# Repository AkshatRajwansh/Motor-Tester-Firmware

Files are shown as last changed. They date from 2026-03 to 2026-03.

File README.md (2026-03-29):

This firmware runs on an onboard Teensy 4.1 MCU in a custom designed PCB for an automated servo motor testing machine. You attach a servo, press a button, and it runs 10 tests automatically \- measuring position accuracy, speed, torque, stall point \- and reports everything on the OLED and over serial. 

### It's split into two phases: 
- Phase 1 (no load, pure motion tests) 
- Phase 2 (with a physical load touching the servo arm, torque/force tests).

Hardware Being Used -
| Device | What it does in this project |
|---|---|
| AS5600 | Magnetic encoder \- reads the actual angle of the servo shaft |
| INA219 | Current + voltage sensor \- measures what the servo is drawing |
| HX711 + Load Cell| Measures force being applied to the servo arm |
| SSD1306 OLED | 128x64 display \- shows live test status |
| SW1 Button | User input \- advances between test phases |
| Servo PWM | The servo motor being tested |

The Custom Designed Schematic is as such - 
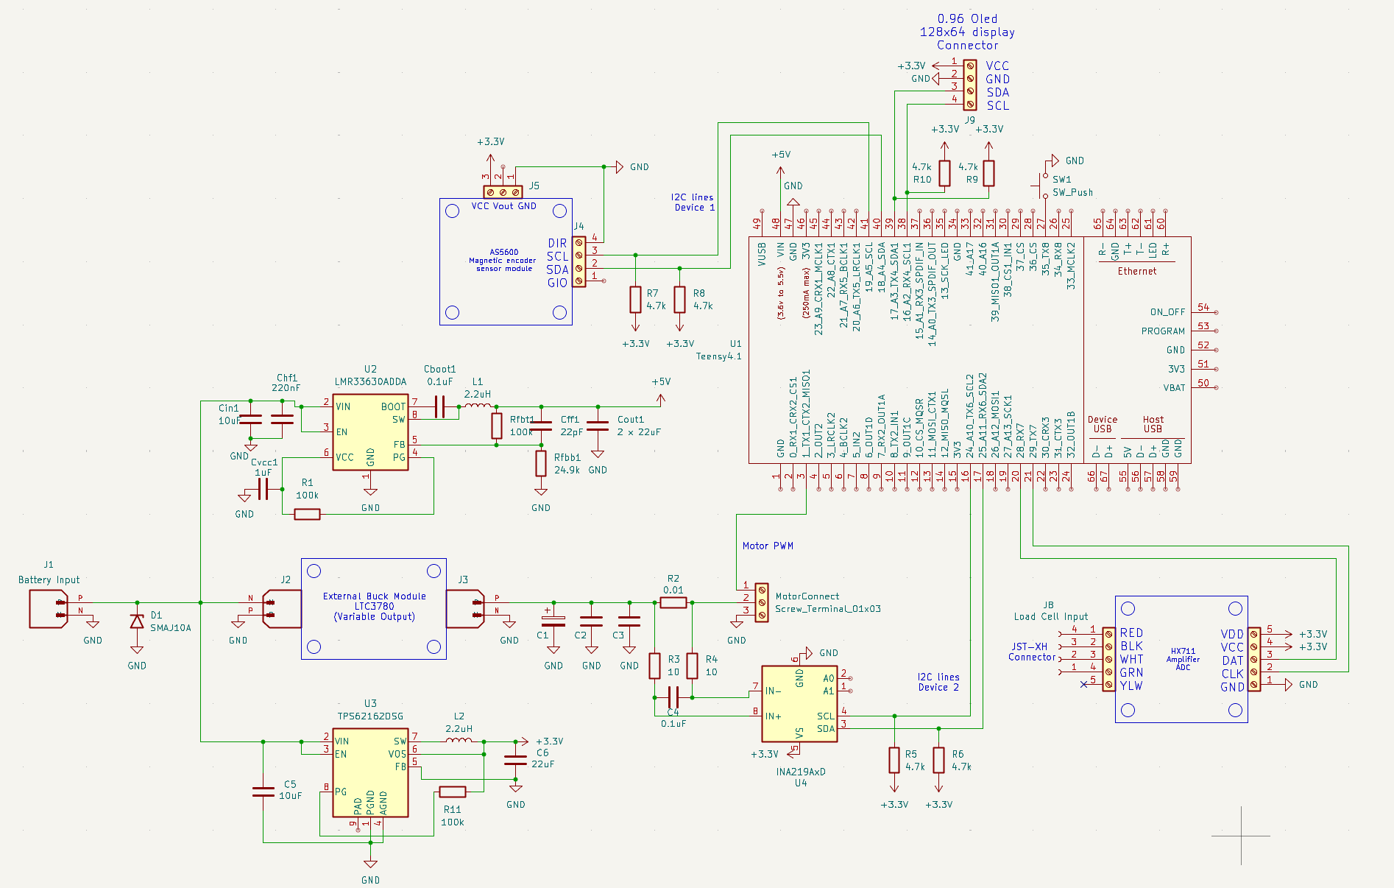
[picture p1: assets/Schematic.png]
PCB Schematic


Here is a detailed explainantion of what is happening in each test and what will be displayed in the OLED screen as well as the serial monitor.

## Phase 1: No Load Tests

### Step 1 - Sweep Test
Moves servo 0°→180°→0° in 2° steps. Records angle, current, and timestamp at every step. Shows if the servo tracks commands accurately while moving and if current spikes at any specific angle.

**OLED Display:**
```
┌─────────────────────────┐
│       SWEEP TEST        │
│ Target:  90.0 deg       │
│ Actual:  89.7 deg       │
│ Current: 210.0 mA       │
│  │
└─────────────────────────┘
```

**Serial Output:**
```
══════════════════════════════════════════════
STEP 1: SWEEP TEST - Angle vs Time vs Current
══════════════════════════════════════════════
  t(ms)  | Target(°) | Actual(°) | Current(mA)
  -------|-----------|-----------|------------
       0 |      0.00 |      0.35 |      142.00
      22 |      2.00 |      2.11 |      198.00
      44 |      4.00 |      3.89 |      210.00
     ...
    1820 |    180.00 |    179.45 |      188.00
```

---

### Step 2 - Position Accuracy
Commands 5 angles (0°, 45°, 90°, 135°, 180°), waits for full settle, then reads actual angle. Computes `error = target - actual` for each. Reveals systematic bias or endpoint inaccuracy.

**OLED Display:**
```
┌─────────────────────────┐
│     POSITION TEST       │
│ Target:   90.0 deg      │
│ Actual:   89.9 deg      │
│ Error:   +0.10 deg      │
└─────────────────────────┘
```

**Serial Output:**
```
══════════════════════════════════════════════
STEP 2: POSITION ACCURACY
══════════════════════════════════════════════
  Target(°) | Actual(°) | Error(°)
  ----------|-----------|----------
       0.00 |      0.35 |   -0.350
      45.00 |     44.82 |   +0.180
      90.00 |     89.91 |   +0.090
     135.00 |    134.76 |   +0.240
     180.00 |    179.44 |   +0.560
  Max absolute error: 0.560°
```

---

### Step 3 - Repeatability
Moves to 90° seven times from 0° each time. Computes mean and standard deviation of the 7 readings. Low stdDev = tight mechanical consistency. High stdDev = backlash or gear play.

**OLED Display:**
```
┌─────────────────────────┐
│     Repeatability       │
│ Run 4: 89.921 deg       │
│ Target: 90 deg          │
└─────────────────────────┘
```

**Serial Output:**
```
══════════════════════════════════════════════
STEP 3: REPEATABILITY (target 90°)
══════════════════════════════════════════════
  Run 1: 89.912°    Run 5: 89.945°
  Run 2: 89.934°    Run 6: 89.908°
  Run 3: 89.898°    Run 7: 89.917°
  Run 4: 89.921°
  Mean:   89.919°
  StdDev: 0.0156°
  Range:  0.0470°
```

---

### Step 4 - Speed & Response
Commands 0°→90° and samples at high speed. Records rise time (how long to reach 90°), overshoot (how far past 90° it went), settling time (when it stops oscillating), and peak current.

**OLED Display:**
```
┌─────────────────────────┐
│       Speed Test        │
│ Ang:91.2  I:540mA       │
│ 0 -> 90 deg             │
└─────────────────────────┘
```

**Serial Output:**
```
══════════════════════════════════════════════
STEP 4: SPEED & RESPONSE (0° → 90°)
══════════════════════════════════════════════
  Rise time (to 90°):  210 ms
  Overshoot:           2.34°
  Settling time:       380 ms
  Peak current:        684.0 mA
```

---

## Phase 2: Load Tests

### Step 6 - Contact Detection
Moves forward slowly in 2° steps until load cell force exceeds threshold. Records the contact angle as the reference point for all torque tests.

**OLED Display:**
```
┌─────────────────────────┐
│     Contact Detect      │
│ Ang:22.0 F:4.2g         │
│ I: 145 mA               │
│ Moving forward...       │
└─────────────────────────┘
```

**Serial Output:**
```
══════════════════════════════════════════════
STEP 6: CONTACT DETECTION
══════════════════════════════════════════════
  Contact angle:  24.00°
  Contact force:  23.4 g
```

---

### Step 7 & 8 - Torque Map
From contact angle, pushes further in steps. At each step records force, angle, current, and voltage. Computes torque (`F × arm length`) and power (`V × I`). Reports peak torque angle with efficiency (`N·mm/mW`).

**OLED Display:**
```
┌─────────────────────────┐
│      TORQUE TEST        │
│ Ang: 36.0  I: 398mA     │
│ Force:   112.5 g        │
│ Torque:  55.18 N.mm     │
└─────────────────────────┘
```

**Serial Output:**
```
══════════════════════════════════════════════
STEP 7 & 8: TORQUE vs ANGLE vs CURRENT
══════════════════════════════════════════════
  Angle(°) | Force(g) | Torque(N·mm) | Current(mA) | Voltage(V) | Power(mW)
  ---------|----------|--------------|-------------|------------|----------
     24.00 |    23.40 |       11.481 |      198.00 |      4.980 |    986.04
     28.00 |    45.80 |       22.467 |      245.00 |      4.975 |   1218.88
     36.00 |   112.50 |       55.181 |      398.00 |      4.955 |   1972.09
     48.00 |   183.20 |       89.865 |      558.00 |      4.920 |   2745.36

  --- Peak Torque Point ---
  Angle:      48.00 deg
  Torque:     89.865 N·mm
  Current:    558.0 mA
  Voltage:    4.920 V
  Power:      2745.36 mW
  Efficiency: 0.0327 N·mm/mW
```

---

### Step 9 - Stall Test
Continues increasing load until both conditions trigger simultaneously: angle stops changing AND current spikes above threshold. Records stall torque, stall current, and stall angle.

**OLED Display:**
```
┌─────────────────────────┐
│       STALL TEST        │
│ Angle:   62.0 deg       │
│ Current:1342.0 mA       │
│ Torque: 118.45 N.mm     │
└─────────────────────────┘
```

**Serial Output:**
```
══════════════════════════════════════════════
STEP 9: STALL TEST
══════════════════════════════════════════════
  Stall angle:   62.00°
  Stall torque:  118.450 N·mm
  Stall current: 1342.0 mA
```

---

### Step 10 - Loaded Hold
Holds 90° for 3 seconds under load. Records position drift and current min/max/avg. Low drift + stable current = good servo. High drift or large current swings = weak holding or internal oscillation.

**OLED Display:**
```
┌─────────────────────────┐
│      TORQUE TEST        │
│ Ang: 89.9  I: 312mA     │
│ Force:    98.2 g        │
│ Torque:   48.16 N.mm    │
└─────────────────────────┘
```

**Serial Output:**
```
══════════════════════════════════════════════
STEP 10: LOADED HOLDING TEST
══════════════════════════════════════════════
  Hold angle:    90.00°
  End angle:     89.87°
  Drift:        -0.1300°
  Avg current:   312.4 mA
  Min current:   287.0 mA
  Max current:   341.0 mA
```

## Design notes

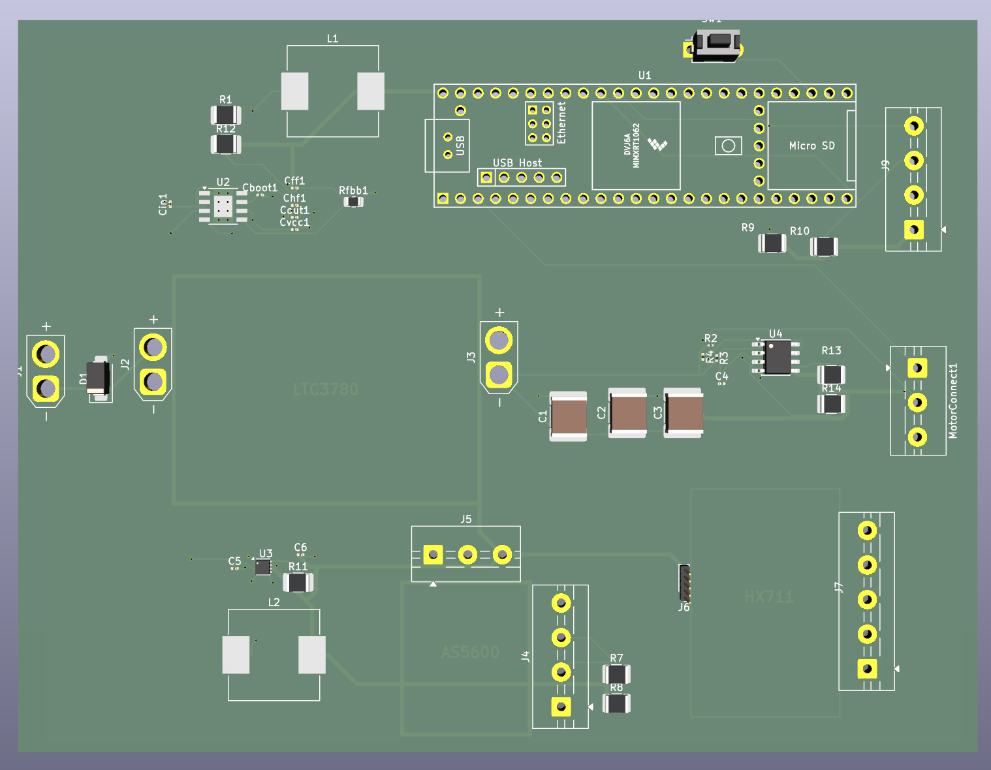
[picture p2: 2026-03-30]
assets/3D View of PCB.png

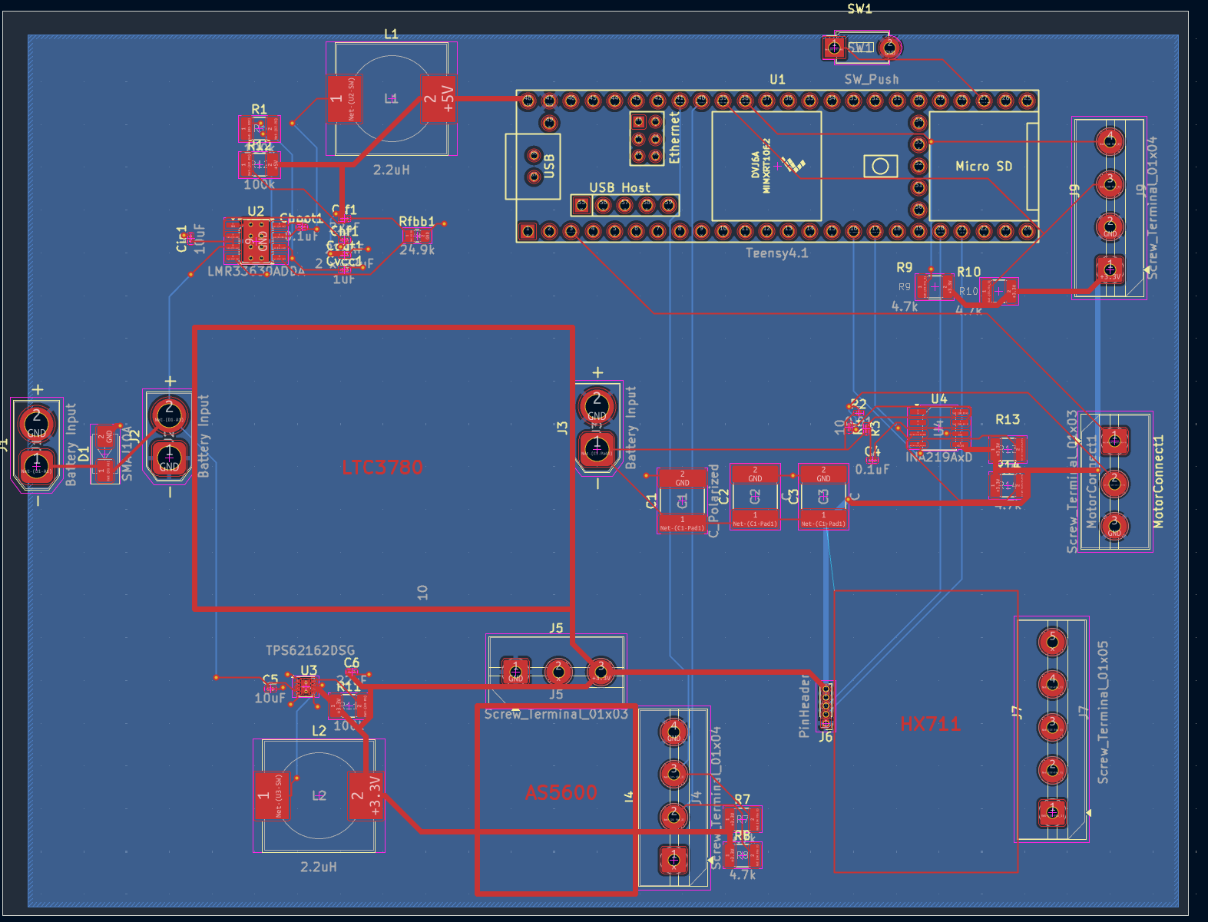
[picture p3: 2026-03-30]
assets/PCB Layout.png

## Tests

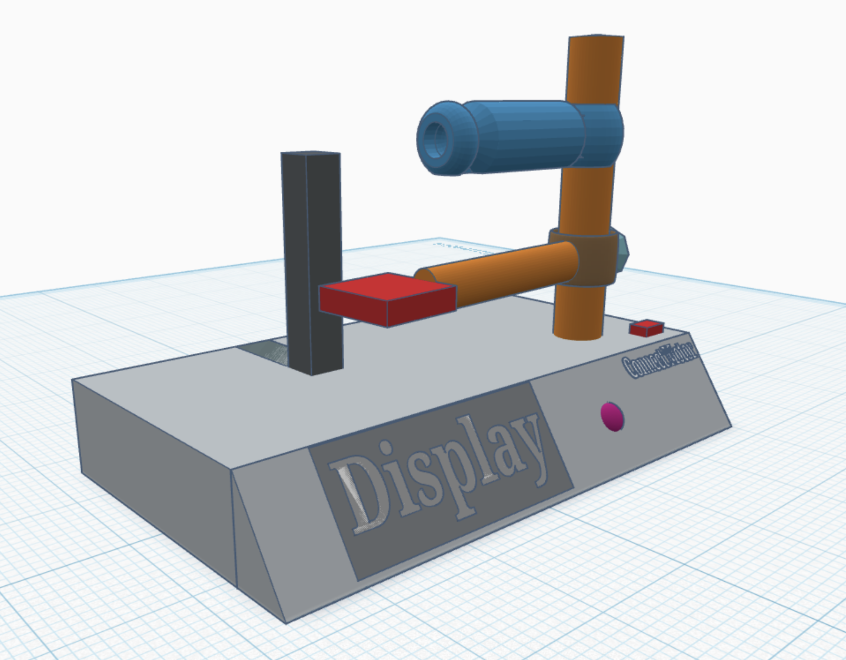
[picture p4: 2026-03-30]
assets/Sketch of Testing Jig.png

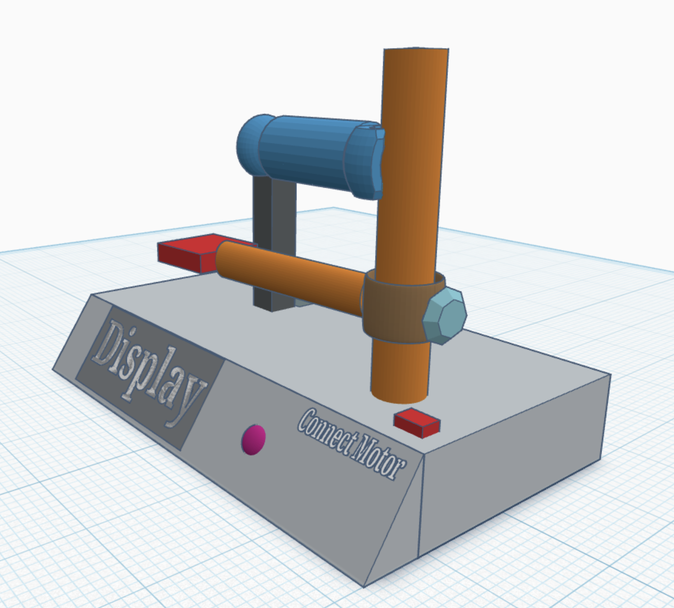
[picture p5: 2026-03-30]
assets/Sketch of Testing Jig 2.png

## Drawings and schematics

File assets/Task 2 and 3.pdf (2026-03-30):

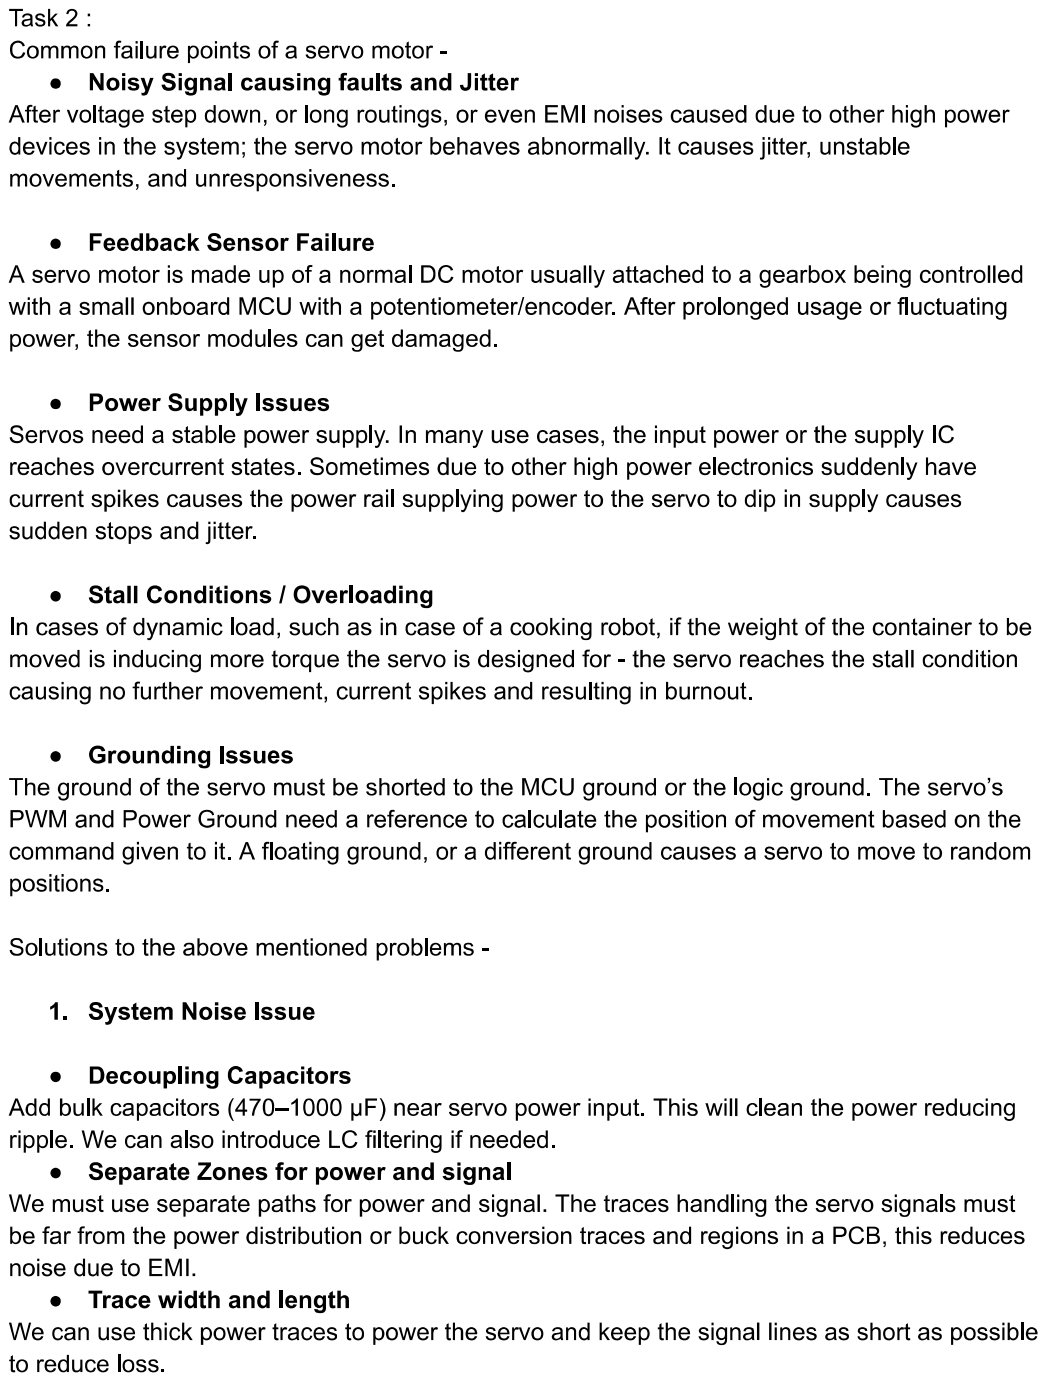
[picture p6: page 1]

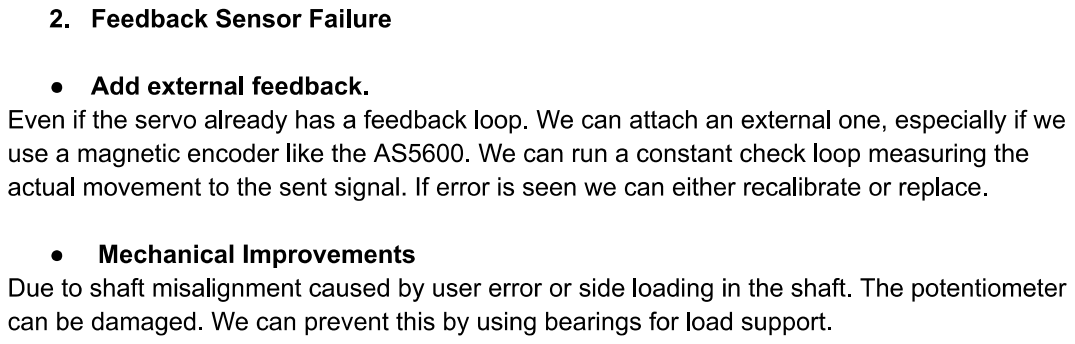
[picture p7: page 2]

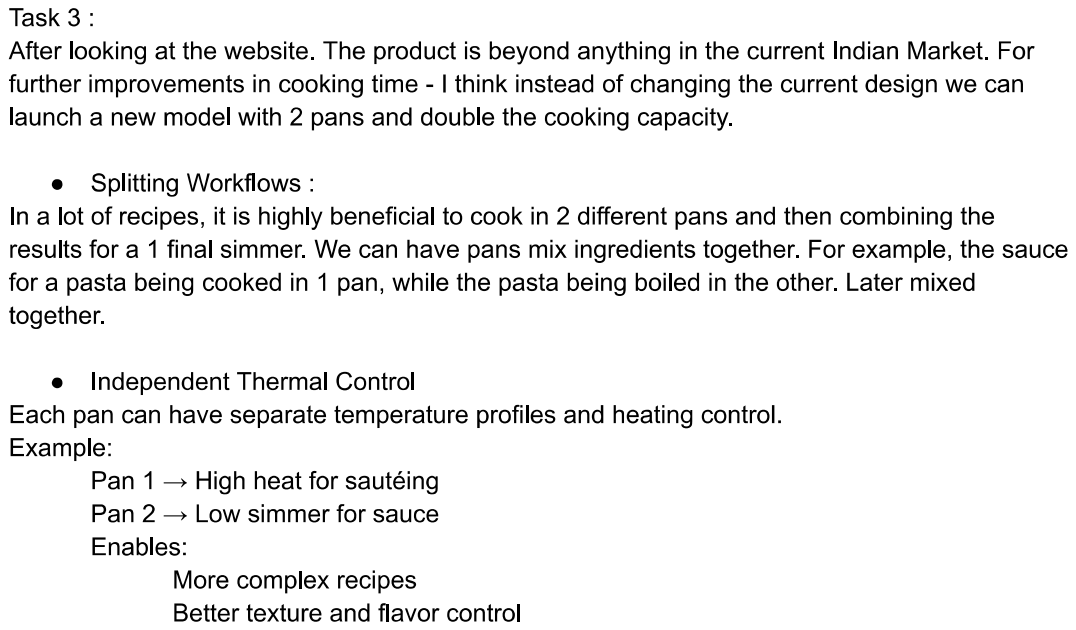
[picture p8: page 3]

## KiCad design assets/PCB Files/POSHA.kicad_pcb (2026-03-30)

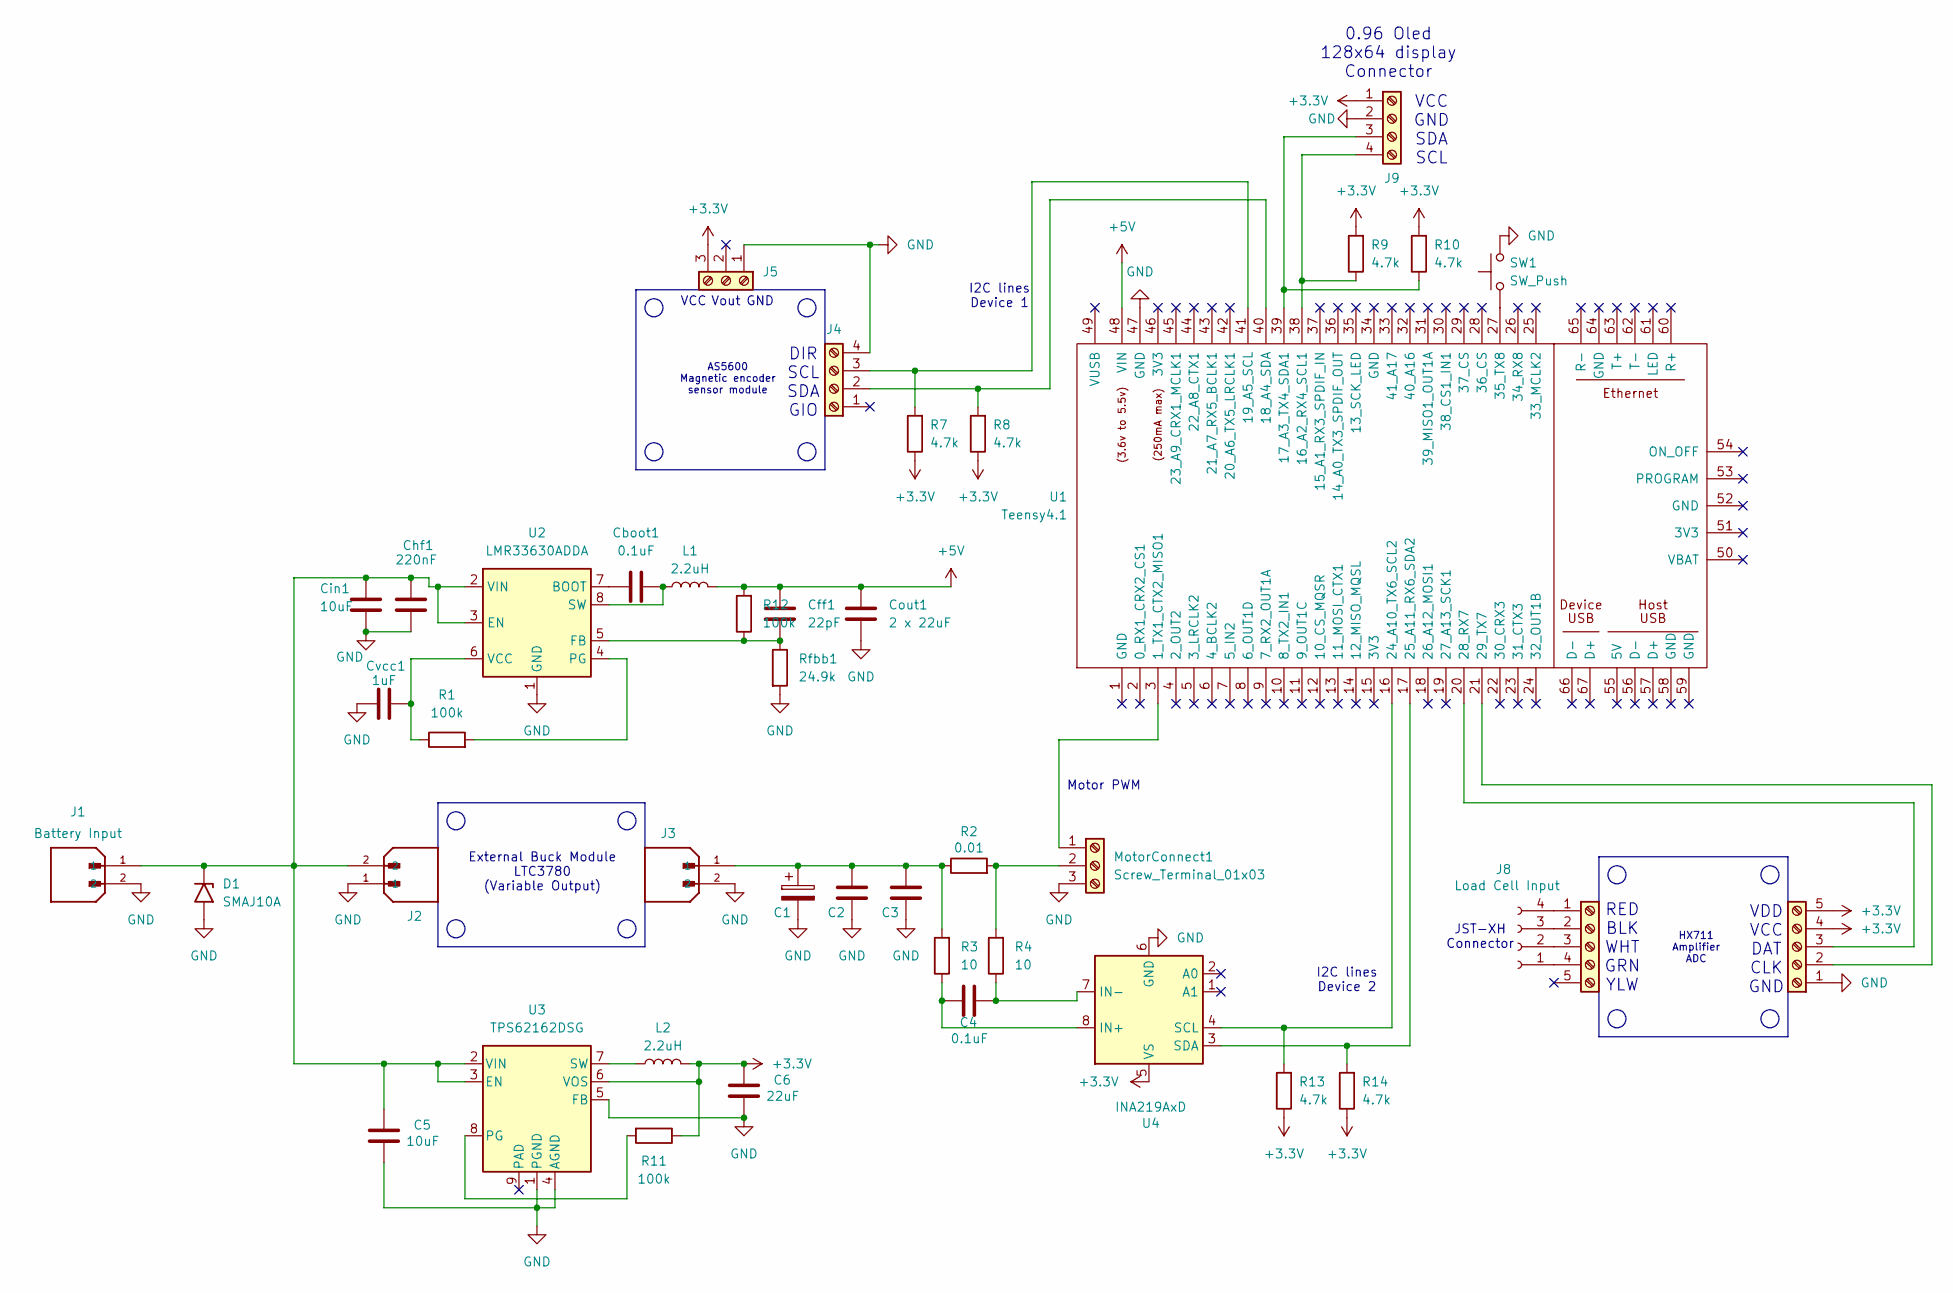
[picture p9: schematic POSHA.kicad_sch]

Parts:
C1: C_Polarized; C_2220_5750Metric_Pad1.97x5.40mm_HandSolder
C2, C3: C; C_2220_5750Metric_Pad1.97x5.40mm_HandSolder
C4: 0.1uF; C_0201_0603Metric
C5: 10uF; C_0201_0603Metric
C6: 22uF; C_0201_0603Metric
Cboot1: 0.1uF; C_0201_0603Metric
Cff1: 22pF; C_0201_0603Metric
Chf1: 220nF; C_0201_0603Metric
Cin1: 10uF; C_0201_0603Metric
Cout1: 2 x 22uF; C_0201_0603Metric
Cvcc1: 1uF; C_0201_0603Metric
D1: SMAJ10A; D_SMA
J1, J2, J3: Battery Input; AMASS_XT30U-F_1x02_P5.0mm_Vertical; PARTREV 1.2
J4, J9: Screw_Terminal_01x04; TerminalBlock_MaiXu_MX126-5.0-04P_1x04_P5.00mm
J5: Screw_Terminal_01x03; TerminalBlock_MaiXu_MX126-5.0-03P_1x03_P5.00mm
J6: Screw_Terminal_01x05; PinHeader_1x05_P1.00mm_Vertical
J7: Screw_Terminal_01x05; TerminalBlock_MaiXu_MX126-5.0-05P_1x05_P5.00mm
J8: Load Cell Input; JST_XH_B4B-XH-A_1x04_P2.50mm_Vertical
L1, L2: 2.2uH; L_Neosid_SM-NE127_HandSoldering
MotorConnect1: Screw_Terminal_01x03; TerminalBlock_MaiXu_MX126-5.0-03P_1x03_P5.00mm
R1, R11, R12: 100k; R_1210_3225Metric_Pad1.30x2.65mm_HandSolder
R2: 0.01; R_01005_0402Metric
R3, R4: 10; R_0201_0603Metric
R7, R8, R9, R10, R13, R14: 4.7k; R_1210_3225Metric
Rfbb1: 24.9k; R_0805_2012Metric
SW1: SW_Push; SW_PUSH_1P1T_6x3.5mm_H5.0_APEM_MJTP1250
U1: Teensy4.1; Teensy41
U2: LMR33630ADDA; Texas_HSOP-8-1EP_3.9x4.9mm_P1.27mm_ThermalVias
U3: TPS62162DSG; WSON-8-1EP_2x2mm_P0.5mm_EP0.9x1.6mm_ThermalVias
U4: INA219AxD; SOIC-8_3.9x4.9mm_P1.27mm

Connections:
+3.3V: C6.1, J5.3, J6.4, J6.5, J9.1, L2.2, R7.1, R8.1, R9.2, R10.2, R11.1, R13.1, R14.1, U3.6 (VOS), U4.5 (VS)
+5V: Cff1.1, Cout1.1, L1.2, R12.2, U1.48 (VIN)
GND: C1.2, C2.2, C3.2, C5.2, C6.2, Chf1.2, Cin1.2, Cout1.2, Cvcc1.2, D1.2 (A2), J1.2, J2.1, J3.2, J4.4, J5.1, J6.1, J9.2, MotorConnect1.3, Rfbb1.2, SW1.2, U1.47 (GND), U2.1 (GND), U2.9 (GND), U3.1 (PGND), U3.4 (AGND), U3.5 (FB), U4.6 (GND)
unnamed: C1.1, C2.1, C3.1, J3.1, R2.1, R3.2
unnamed: C5.1, Chf1.1, Cin1.1, D1.1 (A1), J1.1, J2.2, U2.2 (VIN), U2.3 (EN), U3.2 (VIN), U3.3 (EN)
unnamed: J4.2, R8.2, U1.40 (18_A4_SDA)
unnamed: J4.3, R7.2, U1.41 (19_A5_SCL)
unnamed: J6.2, U1.21 (29_TX7)
unnamed: J6.3, U1.20 (28_RX7)
unnamed: J7.1, J8.4
unnamed: J7.2, J8.3
unnamed: J7.3, J8.2
unnamed: J7.4, J8.1
unnamed: J9.3, R10.1, U1.39 (17_A3_TX4_SDA1)
unnamed: J9.4, R9.1, U1.38 (16_A2_RX4_SCL1)
unnamed: MotorConnect1.1, U1.3 (1_TX1_CTX2_MISO1)
unnamed: MotorConnect1.2, R2.2, R4.2
unnamed: R13.2, U1.16 (24_A10_TX6_SCL2), U4.4 (SCL)
unnamed: R14.2, U1.17 (25_A11_RX6_SDA2), U4.3 (SDA)
unnamed: SW1.1, U1.27 (35_TX8)
unnamed: Cboot1.1, U2.7 (BOOT)
unnamed: Cff1.2, R12.1, Rfbb1.1, U2.5 (FB)
unnamed: R1.2, U2.4 (PG)
unnamed: Cboot1.2, L1.1, U2.8 (SW)
unnamed: Cvcc1.1, R1.1, U2.6 (VCC)
unnamed: R11.2, U3.8 (PG)
unnamed: L2.1, U3.7 (SW)
unnamed: C4.1, R3.1, U4.8 (IN+)
unnamed: C4.2, R4.1, U4.7 (IN-)

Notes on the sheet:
Vout
I2C lines Device 1
VCC
Motor PWM
AS5600 Magnetic encoder sensor module
0.96 Oled 128x64 display Connector
JST-XH Connector
DIR SCL SDA GIO
RED BLK WHT GRN YLW
VDD VCC DAT CLK GND
GND
External Buck Module LTC3780 (Variable Output)
I2C lines Device 2
HX711 Amplifier ADC
VCC GND SDA SCL

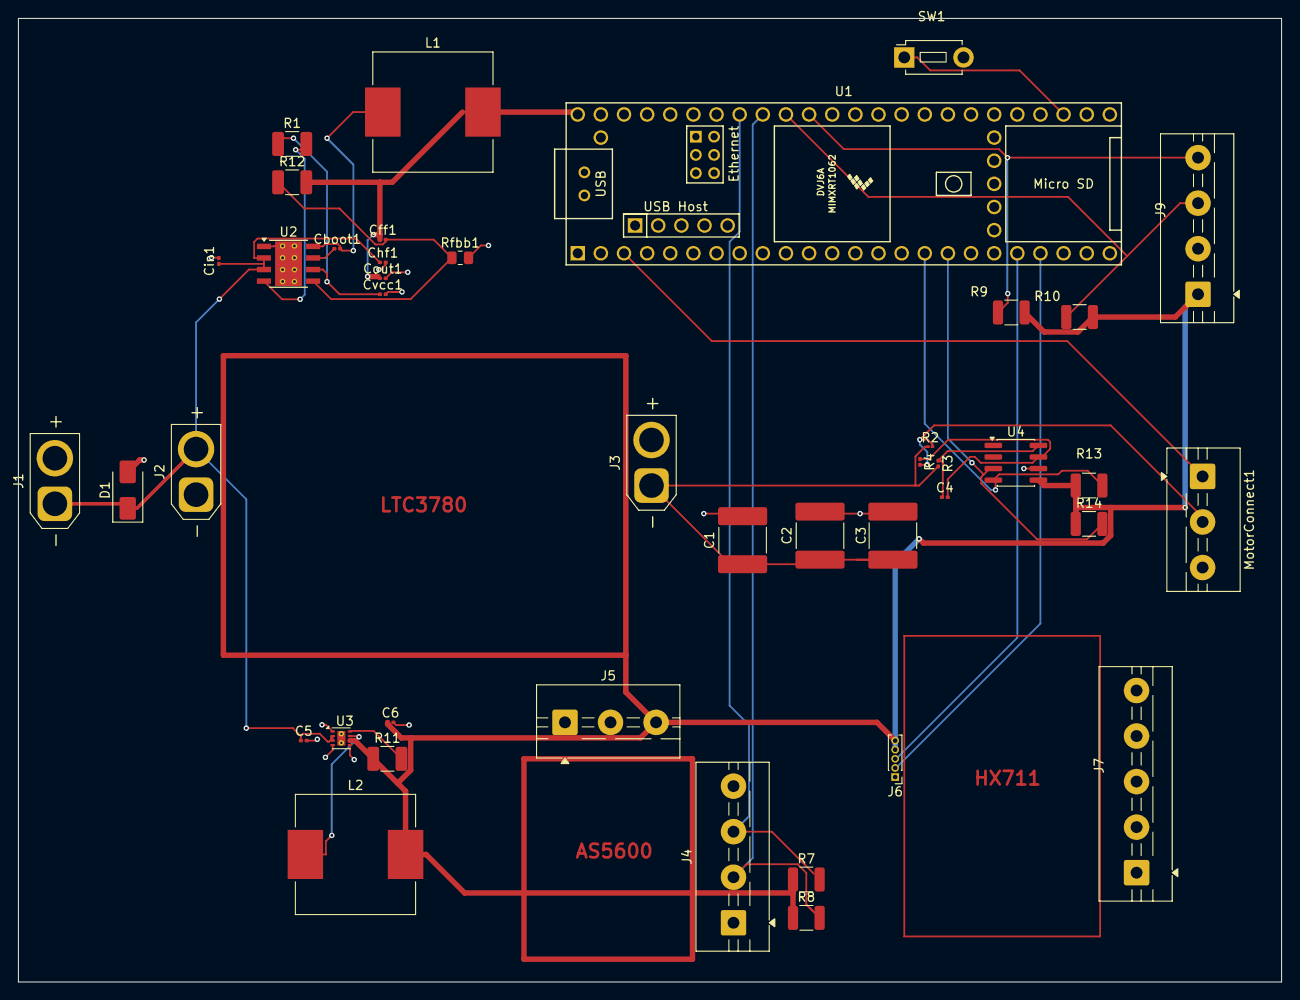
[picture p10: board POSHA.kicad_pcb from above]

Board: 2 copper layers, 138.7 x 105.8 mm, 42 parts (0 on the bottom side), 25 nets.

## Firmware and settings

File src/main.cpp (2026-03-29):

#include <Arduino.h>
#include <Wire.h>
#include <Adafruit_INA219.h>
#include <HX711.h>

#include "config.h"
#include "as5600.h"
#include "display_manager.h"
#include "servo_ctrl.h"
#include "test_results.h"
#include "report.h"

DisplayManager  display;
AS5600Driver    encoder;
ServoController servo;
Adafruit_INA219 ina219(INA219_I2C_ADDR);
HX711           loadCell;

TestResults results;

// define the 8 STeps
enum class AppState {
    WELCOME,
    PHASE1_STARTING,
    STEP1_SWEEP,
    STEP2_POSITION,
    STEP3_REPEAT,
    STEP4_SPEED,
    PHASE1_RESULTS,
    WAIT_PHASE2,
    PHASE2_STARTING,
    STEP6_CONTACT,
    STEP7_TORQUE,
    STEP9_STALL,
    STEP10_HOLD,
    PHASE2_RESULTS,
    DONE
};

AppState appState = AppState::WELCOME;

// button press check, also 50ms hold time so normal noise is not confused with actual press
bool buttonPressed() {
    if (digitalRead(BUTTON_PIN) == LOW) {
        delay(50);
        if (digitalRead(BUTTON_PIN) == LOW) {
            while (digitalRead(BUTTON_PIN) == LOW) delay(10);
            return true;
        }
    }
    return false;
}

void waitForButton() {
    while (!buttonPressed()) delay(20);
}

// Sensor reads
float readCurrentMA() {
    return ina219.getCurrent_mA();
}

float readForceGrams() {
    if (loadCell.is_ready()) {
        float raw = loadCell.get_units(3);  // average of 3 readings, normal usage in library
        return raw;                          
    }
    return 0.0f;
}

float readAngleDeg() {
    return encoder.readZeroedDegrees();
}

// STEP 1: Sweep Test
void runSweepTest() {
    display.showPhaseHeader("1: Sweep Test");
    delay(800);

    results.sweepCount = 0;
    uint32_t startMs = millis();

    // Forward: 0 → 180
    for (float target = 0; target <= 180.0f; target += 2.0f) {
        servo.moveTo(target);
        delay(20);
        float actual  = readAngleDeg();
        float current = readCurrentMA();

        if (results.sweepCount < 200) {
            results.sweepData[results.sweepCount++] = {
                target, actual, current, millis() - startMs
            };
        }
        display.showSweep(actual, current, target);
    }

    // Reverse: 180 → 0
    for (float target = 180.0f; target >= 0; target -= 2.0f) {
        servo.moveTo(target);
        delay(20);
        float actual  = readAngleDeg();
        float current = readCurrentMA();

        if (results.sweepCount < 200) {
            results.sweepData[results.sweepCount++] = {
                target, actual, current, millis() - startMs
            };
        }
        display.showSweep(actual, current, target);
    }

    ReportPrinter::printSweepData(results);
    display.showStatus("Step 1 Done", "Sweep complete", "See serial log");
    delay(1500);
}

// STEP 2: Position Accuracy
void runPositionAccuracyTest() {
    const float targets[] = {0.0f, 45.0f, 90.0f, 135.0f, 180.0f};
    results.posCount = 0;

    for (uint8_t i = 0; i < 5; i++) {
        float target = targets[i];
        servo.moveTo(target);
        delay(SETTLE_TIME_MS);

        float actual = readAngleDeg();
        float error  = target - actual;

        results.posResults[results.posCount++] = {target, actual, error};
        display.showPositionTest(target, actual, error);

        char buf[24];
        snprintf(buf, sizeof(buf), "Target %.0f -> %.2f err", target, error);
#if SERIAL_DEBUG
        Serial.println(buf);
#endif
        delay(600);
    }

    ReportPrinter::printPositionAccuracy(results);
}

// STEP 3: Repeatability 
void runRepeatabilityTest() {
    display.showPhaseHeader("3: Repeatability");
    delay(500);

    results.repeat.count = REPEATABILITY_RUNS;

    for (uint8_t run = 0; run < REPEATABILITY_RUNS; run++) {
        // Start from 0
        servo.moveTo(0);
        delay(300);

        // Move to 90
        servo.moveTo(90);
        delay(SETTLE_TIME_MS);

        float actual = readAngleDeg();
        results.repeat.positions[run] = actual;

        char buf[28];
        snprintf(buf, sizeof(buf), "Run %d: %.3f deg", run + 1, actual);
        display.showStatus("Repeatability", buf,
                           run == 0 ? "Target: 90 deg" : nullptr);
#if SERIAL_DEBUG
        Serial.println(buf);
#endif
        delay(400);
    }

    results.repeat.mean   = computeMean(results.repeat.positions, REPEATABILITY_RUNS);
    results.repeat.stdDev = computeStdDev(results.repeat.positions,
                                           REPEATABILITY_RUNS, results.repeat.mean);
    ReportPrinter::printRepeatability(results);
}

// STEP 4: Speed & Response 
void runSpeedTest() {
    display.showPhaseHeader("4: Speed Test");
    delay(500);

    servo.moveTo(0);
    delay(400);

    float    peakI     = 0;
    float    peakAngle = 0;
    uint32_t t0        = millis();
    uint32_t tSettle   = 0;
    bool     reached90 = false;
    uint32_t t90       = 0;

    servo.moveTo(90);

    // Sample for 2 seconds after command
    uint32_t sampleEnd = millis() + 2000;
    while (millis() < sampleEnd) {
        float angle   = readAngleDeg();
        float current = readCurrentMA();

        if (current > peakI)    peakI    = current;
        if (angle   > peakAngle) peakAngle = angle;
        if (!reached90 && angle >= 90.0f) {
            reached90 = true;
            t90 = millis() - t0;
        }

        char buf[28];
        snprintf(buf, sizeof(buf), "Ang:%.1f I:%.0fmA", angle, current);
        display.showStatus("Speed Test", buf, "0 -> 90 deg");
    }

    // Measure settle: within ±1° of 90 after peak
    float finalAngle = readAngleDeg();
    float overshoot  = max(0.0f, peakAngle - 90.0f);

    // Crude settle time: wait until stable within 0.5°
    uint32_t settleStart = millis();
    uint32_t settleTime  = 0;
    bool settled = false;
    while (millis() - settleStart < 1500 && !settled) {
        float a = readAngleDeg();
        if (abs(a - 90.0f) < 0.5f) {
            settleTime = millis() - t0;
            settled = true;
        }
        delay(10);
    }

    results.speed = {t90, overshoot, settleTime, peakI};
    ReportPrinter::printSpeedResponse(results);
}

// ── STEP 6: Contact Detection ─────────────────────────────────
void runContactDetection() {
    display.showPhaseHeader("6: Contact Detect");
    display.showStatus("Contact Detect", "Attach load now", "Move slowly fwd");
    delay(2000);

    servo.moveTo(0);
    delay(400);

    float contactAngle = 0;
    float contactForce = 0;
    bool  found = false;

    for (float angle = 0; angle <= 180.0f && !found; angle += SWEEP_STEP_DEG) {
        servo.moveTo(angle);
        delay(SWEEP_STEP_DELAY_MS);

        float force   = readForceGrams();
        float current = readCurrentMA();

        char buf[28];
        snprintf(buf, sizeof(buf), "Ang:%.1f F:%.1fg", angle, force);
        display.showStatus("Contact Detect", buf, "Moving forward...");

        if (force > LOAD_CONTACT_THRESHOLD_G) {
            contactAngle = angle;
            contactForce = force;
            found = true;
        }
    }

    results.contact = {contactAngle, contactForce};

    if (found) {
        char buf[32];
        snprintf(buf, sizeof(buf), "Contact @ %.1f deg", contactAngle);
        display.showStatus("Contact Found!", buf);
        Serial.printf("[CONTACT] Angle: %.2f°  Force: %.1f g\n",
                      contactAngle, contactForce);
    } else {
        display.showStatus("Contact Detect", "No contact found!", "Check load cell");
        Serial.println("[CONTACT] No contact detected — check load cell calibration");
        delay(2000);
    }
    delay(1000);
}

// STEP 7 & 8: Torque vs Angle vs Current
void runTorqueTest() {
    display.showPhaseHeader("7&8: Torque Map");
    delay(500);

    results.torqueCount = 0;
    float startAngle = results.contact.contactAngleDeg;

    for (float angle = startAngle; angle <= 180.0f && results.torqueCount < 50;
         angle += SWEEP_STEP_DEG * 2) {

        servo.moveTo(angle);
        delay(SWEEP_STEP_DELAY_MS * 2);

        float force   = readForceGrams();
        float current = readCurrentMA();
        // Torque = Force[N] × Arm[m] ; force in grams → N: /1000 * 9.81
        // ARM_LENGTH_MM → m: /1000
        float torqueNmm = (force / 1000.0f * 9.81f) * ARM_LENGTH_MM;

        results.torqueData[results.torqueCount++] = {angle, force, torqueNmm, current};
        display.showTorque(angle, force, torqueNmm, current);

        Serial.printf("[TORQUE] Ang:%.1f° F:%.1fg Tq:%.3fN·mm I:%.1fmA\n",
                      angle, force, torqueNmm, current);
    }

    ReportPrinter::printTorqueData(results);
}

// STEP 9: Stall Test 
void runStallTest() {
    display.showPhaseHeader("9: Stall Test");
    delay(500);

    float lastAngle     = readAngleDeg();
    float stallAngle    = 0;
    float stallTorque   = 0;
    float stallCurrent  = 0;
    bool  stalled       = false;

    for (float angle = results.contact.contactAngleDeg;
         angle <= 180.0f && !stalled;
         angle += SWEEP_STEP_DEG) {

        servo.moveTo(angle);
        delay(SWEEP_STEP_DELAY_MS + 20);

        float actualAngle = readAngleDeg();
        float force       = readForceGrams();
        float current     = readCurrentMA();
        float torque      = (force / 1000.0f * 9.81f) * ARM_LENGTH_MM;

        display.showStall(actualAngle, current, torque);

        bool angleStuck   = abs(actualAngle - lastAngle) < STALL_ANGLE_DEAD_DEG;
        bool currentSpike = current > STALL_CURRENT_MA;

        if (angleStuck && currentSpike) {
            stallAngle   = actualAngle;
            stallTorque  = torque;
            stallCurrent = current;
            stalled      = true;
            Serial.printf("[STALL] Detected at %.2f°, Tq=%.3f N·mm, I=%.1f mA\n",
                          stallAngle, stallTorque, stallCurrent);
        }

        lastAngle = actualAngle;
    }

    if (!stalled) {
        // Record whatever we got at the end
        stallAngle   = readAngleDeg();
        stallCurrent = readCurrentMA();
        float f      = readForceGrams();
        stallTorque  = (f / 1000.0f * 9.81f) * ARM_LENGTH_MM;
        Serial.println("[STALL] No stall detected before 180°");
    }

    results.stall = {stallAngle, stallTorque, stallCurrent};
    ReportPrinter::printStall(results);
}

// STEP 10: Loaded Holding Test 
void runHoldTest() {
    display.showPhaseHeader("10: Hold Test");
    delay(500);

    float holdAngle = 90.0f;
    servo.moveTo(holdAngle);
    delay(SETTLE_TIME_MS);

    float startAngle = readAngleDeg();
    float sumI = 0, minI = 1e6f, maxI = 0;
    int   samples = 0;

    uint32_t holdStart = millis();
    while (millis() - holdStart < HOLDING_DURATION_MS) {
        float angle   = readAngleDeg();
        float force   = readForceGrams();
        float current = readCurrentMA();
        float torque  = (force / 1000.0f * 9.81f) * ARM_LENGTH_MM;

        sumI += current;
        if (current < minI) minI = current;
        if (current > maxI) maxI = current;
        samples++;

        display.showTorque(angle, force, torque, current);
        delay(50);
    }

    float endAngle = readAngleDeg();
    float avgI     = (samples > 0) ? sumI / samples : 0;

    results.hold = {startAngle, endAngle, endAngle - startAngle, avgI, minI, maxI};
    ReportPrinter::printHold(results);
}

// ═════════════════════════════════════════════════════════════
//  setup()
// ═════════════════════════════════════════════════════════════
void setup() {
    Serial.begin(115200);
    delay(1500);
    Serial.println("=== Servo Test JIG Booting ===");

    pinMode(BUTTON_PIN, INPUT_PULLUP);

    // ── I2C Bus 0: OLED + AS5600 ─────────────────────────────
    Wire.begin();            // Bus 0 → AS5600
    Wire.setClock(400000);
    Wire1.begin();           // Bus 1 → OLED
    Wire1.setClock(400000);

    if (!display.begin()) {
        Serial.println("ERROR: OLED not found");
        while (1) {}
    }
    display.showStatus("Booting...", "OLED OK");
    Serial.println("[OK] OLED");

    if (!encoder.begin()) {
        display.showError("AS5600 not found!");
        Serial.println("ERROR: AS5600 not found");
        while (1) {}
    }
    if (!encoder.magnetDetected()) {
        display.showError("No magnet!");
        Serial.println("WARNING: AS5600 magnet not detected");
    }
    display.showStatus("Booting...", "Encoder OK");
    Serial.println("[OK] AS5600");

    // ── I2C Bus 2: INA219 ─────────────────────────────────────
    Wire2.begin();
    Wire2.setClock(400000);
    // Point INA219 library to Wire2
    // Note: Adafruit_INA219 uses Wire by default; we pass &Wire2 here
    // via a modified constructor — if using standard lib, change address pins
    // to match or re-route Wire2 SDA/SCL at board level
    ina219 = Adafruit_INA219(INA219_I2C_ADDR);
    if (!ina219.begin(&Wire2)) {
        display.showError("INA219 not found!");
        Serial.println("ERROR: INA219 not found on Wire2");
        while (1) {}
    }
    ina219.setCalibration_32V_2A();
    display.showStatus("Booting...", "INA219 OK");
    Serial.println("[OK] INA219");

    // ── HX711 Load Cell ───────────────────────────────────────
    loadCell.begin(HX711_DAT_PIN, HX711_CLK_PIN);
    loadCell.set_scale(2280.f);  // ← calibrate this value for your load cell
    loadCell.tare();
    display.showStatus("Booting...", "HX711 OK", "Tared");
    Serial.println("[OK] HX711 tared");

    // ── Servo ─────────────────────────────────────────────────
    servo.begin();
    Serial.println("[OK] Servo attached");

    // ── Zero encoder at rest ──────────────────────────────────
    delay(300);
    encoder.zero();
    Serial.println("[OK] Encoder zeroed");

    memset(&results, 0, sizeof(results));
    delay(800);
    appState = AppState::WELCOME;
}

// now just calling functions in order
void loop() {
    switch (appState) {

    case AppState::WELCOME:
        display.showWelcome();
        waitForButton();
        appState = AppState::PHASE1_STARTING;
        break;

    case AppState::PHASE1_STARTING:
        display.showStatus("Phase 1", "Starting...", "Position Tests");
        Serial.println("\n>>> PHASE 1: POSITION TESTS <<<");
        delay(1000);
        appState = AppState::STEP1_SWEEP;
        break;

    case AppState::STEP1_SWEEP:
        display.showPhaseHeader("1: Sweep Test");
        delay(600);
        runSweepTest();
        appState = AppState::STEP2_POSITION;
        break;

    case AppState::STEP2_POSITION:
        display.showPhaseHeader("2: Position Test");
        delay(600);
        runPositionAccuracyTest();
        appState = AppState::STEP3_REPEAT;
        break;

    case AppState::STEP3_REPEAT:
        runRepeatabilityTest();
        appState = AppState::STEP4_SPEED;
        break;

    case AppState::STEP4_SPEED:
        runSpeedTest();
        appState = AppState::PHASE1_RESULTS;
        break;

    case AppState::PHASE1_RESULTS: {
        float maxErr = computeMaxAbsError(results.posResults, results.posCount);
        display.showResultsPhase1(
            maxErr,
            results.repeat.stdDev,
            (float)results.speed.time0to90Ms,
            results.speed.overshootDeg,
            results.speed.peakCurrentMA);
        ReportPrinter::printPhase1Summary(results);

        delay(3000);
        display.showPressButton("Phase 2: Load Tests");
        Serial.println("\nAttach load to servo arm, then press button...");
        waitForButton();
        appState = AppState::PHASE2_STARTING;
        break;
    }

    case AppState::PHASE2_STARTING:
        display.showStatus("Phase 2", "Load Tests", "Starting...");
        Serial.println("\n>>> PHASE 2: LOAD / TORQUE TESTS <<<");
        loadCell.tare();  // re-tare before load tests
        delay(1000);
        appState = AppState::STEP6_CONTACT;
        break;

    case AppState::STEP6_CONTACT:
        runContactDetection();
        appState = AppState::STEP7_TORQUE;
        break;

    case AppState::STEP7_TORQUE:
        runTorqueTest();
        appState = AppState::STEP9_STALL;
        break;

    case AppState::STEP9_STALL:
        runStallTest();
        appState = AppState::STEP10_HOLD;
        break;

    case AppState::STEP10_HOLD:
        runHoldTest();
        appState = AppState::PHASE2_RESULTS;
        break;

    case AppState::PHASE2_RESULTS:
        display.showResultsPhase2(
            results.stall.stallTorqueNmm,
            results.stall.stallCurrentMA,
            results.stall.stallAngleDeg,
            results.hold.driftDeg);
        ReportPrinter::printPhase2Summary(results);
        delay(5000);
        appState = AppState::DONE;
        break;

    // Final
    case AppState::DONE:
        display.showDone();
        servo.moveTo(0);
        // Halt — reset board to restart
        while (true) delay(1000);
        break;
    }
}

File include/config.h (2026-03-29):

#pragma once

// I2C Bus assignments 
// Wire  (Bus 0) : pins 18 SDA / 19 SCL  → AS5600
// Wire1 (Bus 1) : pins 17 SDA / 16 SCL  → OLED
// Wire2 (Bus 2) : pins 24 SDA / 25 SCL  → INA219

#define AS5600_I2C_ADDR     0x36  
#define OLED_I2C_ADDR       0x3C   
#define INA219_I2C_ADDR     0x40   

#define HX711_DAT_PIN       3      
#define HX711_CLK_PIN       2      

#define SERVO_PWM_PIN       9      
#define SERVO_MIN_US        500    
#define SERVO_MAX_US        2500   

#define BUTTON_PIN          0      

#define OLED_WIDTH          128
#define OLED_HEIGHT         64
#define OLED_RESET_PIN      -1     

// ── Test Parameters 
#define ARM_LENGTH_MM       50.0f  // torque arm length in mm adjust to your fixture
#define LOAD_CONTACT_THRESHOLD_G  20.0f   // grams contact detection force threshold
#define SETTLE_TIME_MS      400    // ms to wait after commanding position
#define STALL_CURRENT_MA    1200.0f  // mA stall detection threshold
#define STALL_ANGLE_DEAD_DEG 1.0f  // deg angle must change by this to be considered moving
#define REPEATABILITY_RUNS  7      // number of runs for repeatability test
#define HOLDING_DURATION_MS 3000   // ms for loaded hold test
#define SWEEP_STEP_DEG      2      // degrees per step during slow sweep (contact detect)
#define SWEEP_STEP_DELAY_MS 30     // ms between steps during slow sweep

#define SERIAL_DEBUG        1      // 1 = enable verbose serial logging

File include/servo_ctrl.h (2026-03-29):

#pragma once
#include <Arduino.h>
#include <Servo.h>
#include "config.h"

class ServoController {
public:
    ServoController() : _currentDeg(0) {}

    void begin() {
        _servo.attach(SERVO_PWM_PIN, SERVO_MIN_US, SERVO_MAX_US);
        moveTo(0);
    }

    // Instantly command angle
    void moveTo(float deg) {
        deg = constrain(deg, 0.0f, 180.0f);
        _currentDeg = deg;
        _servo.write((int)deg);
    }

    // movement with steps and delay
    void smoothMoveTo(float targetDeg, int stepDeg = 1, int stepDelayMs = 15) {
        float start = _currentDeg;
        float diff  = targetDeg - start;
        int steps   = (int)(abs(diff) / stepDeg) + 1;
        for (int i = 1; i <= steps; i++) {
            float interp = start + diff * ((float)i / steps);
            moveTo(interp);
            delay(stepDelayMs);
        }
        moveTo(targetDeg);
    }

    float currentDeg() const { return _currentDeg; }

    void detach() { _servo.detach(); }

private:
    Servo _servo;
    float _currentDeg;
};

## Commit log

2026-03-29 Moved OLED to seperate wire
2026-03-29 Added schematic file and fixed display error
    [POSHA.kicad_sch]
2026-03-29 Modified result calculation and added PCB Current Status
2026-03-30 Added PCB Files
    [POSHA.kicad_pcb, POSHA.kicad_sch]
